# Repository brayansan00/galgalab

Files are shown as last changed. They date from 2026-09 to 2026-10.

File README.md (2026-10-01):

# GalgaLab

Comparación de teoría de vigas, ensayo con galga extensiométrica y FEM de una viga tubular de aluminio 1100. Revisión del ZIP frente a `main` en el commit `dfa231fbb436338dee7460102a4b27766cca2854` (30 de septiembre de 2026).

## Estado y resultados

El cálculo y el tratamiento del CSV son reproducibles. La validación física sigue pendiente: no se recuerda si el herraje de 73 g estaba instalado al poner la galga en cero. Se conservan ambos casos, sin escoger uno como confirmado.

| Referencia experimental | Carga incremental | Teoría en la galga | Diferencia del ensayo respecto a teoría |
|---|---:|---:|---:|
| Herraje añadido después del cero | 49,76613 N | 11,39852 MPa; 165,1959 µε | +10,08 % |
| Herraje presente al poner en cero | 49,05000 N | 11,23449 MPa; 162,8187 µε | +11,69 % |

El ensayo da 185,31171 µε en la meseta; la base previa es 3,46042 µε. El incremento es 181,85128 µε y su esfuerzo equivalente uniaxial es 12,54774 MPa con E = 69 GPa. La desviación de la meseta (0,86 µε) es dispersión de muestras, no incertidumbre total.

Las cifras suponen que el canal exportado ya contiene deformación adimensional y que la rejilla está centrada en la marca CAD y alineada con el eje longitudinal **y**. Falta comprobarlo con el montaje y la configuración de adquisición.

**FEM en revisión.** Las mallas usaron dos fuerzas de 24,883 N en y = 707 mm, con componente vertical conjunta de 46,764 N y gravedad activa. El informe histórico del 24 de septiembre contiene otra configuración: dos fuerzas de 28,106 N y total vertical 52,822 N más gravedad. Las exportaciones anteriores de 10 y 15 mm repetían recuentos y resúmenes; la nueva exportación de 15 mm corrige esa repetición.

**Actualización del 30 de septiembre:** los nuevos informes tienen 80 346 nodos / 40 572 elementos para 10 mm y 48 735 / 24 301 para 15 mm. Las capturas, identificadas como Von Mises por el usuario, dan 10,984 y 10,926 MPa en el mismo punto (17; 205; 29,997) mm: variación de 0,528 % respecto a la malla refinada. Es evidencia de estabilidad puntual entre dos mallas; falta confirmar convergencia con otro refinamiento y comparar la magnitud longitudinal en la rejilla. Véase `fem/mesh_study/actualizacion_2026-09-30/README.md`.

## Reproducir

Desde la raíz del repositorio:

```text
python -m pip install -r requirements.txt
python python/analisis_viga.py
python python/auditar_fem.py
python -m unittest discover -s tests -v
```

El análisis acepta `--csv RUTA`, `--baseline INICIO FIN`, `--plateau INICIO FIN` y `--output-dir CARPETA`. Las ventanas por defecto son inclusivas: base 11–16,5 s (551 muestras), meseta 24–53 s (2 901 muestras). El CSV original conserva 7 744 muestras y 77,43 s a 100 Hz. Se rechazan archivos o ventanas inválidos.

## Archivos

- `python/analisis_viga.py`: modelo, ensayo, sensibilidad de espesor y figuras; `analytical_model.py` conserva la entrada anterior.
- `experimental/raw_data/`: originales; se conservan tanto el archivo previo del grupo 1 como el ensayo Samuel–Brayan. Solo este último alimenta el análisis por defecto.
- `experimental/processed_data/`: señal procesada y resultados JSON, con huella SHA-256 del original.
- `cad/`: STEP actualizado, archivo nativo recibido y verificación geométrica. El archivo Fusion no se ha resuelto ni editado.
- `fem/`: informes vigentes de 10 y 15 mm, exportaciones anteriores conservadas en `mesh_study/historico_2026-09-25/`, auditoría y procedimiento para nuevas corridas.
- `figures/`: gráficas calculadas; `report/informe_viga.tex`: borrador revisado, autónomo con figuras vectoriales incorporadas.
- `report/informe_viga_revisado.pdf`: versión de lectura generada desde los resultados; la compilación LaTeX del editor integrado falló por un problema de entorno y no está verificada.
- `report/original/`: PDF y fuente recibidos, archivados como borrador anterior; no representan la revisión actual.
- `REVISION_CAMBIOS.md`: comparación, opinión y pendientes.

## Para cerrar la validación

Confirmar orientación y centro real de la rejilla, espesor medido, posición de carga y estado de referencia; configurar apoyo y contactos; repetir mallas con la misma carga incremental; comparar **εyy promediada sobre la rejilla** y σyy local, y verificar equilibrio sumando reacciones. Von Mises máximo global no sustituye la lectura de la galga.

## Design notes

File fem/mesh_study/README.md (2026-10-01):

# Estudio de malla

Las mallas de **10 y 15 mm** se actualizaron con los informes y capturas exportados el 30 de septiembre de 2026. Los HTML se conservan completos y las capturas mantienen su formato PNG original. Las imágenes anteriores de esas dos mallas se sustituyeron; Git conserva sus versiones previas.

| Malla | Informe de Fusion | Captura | Nodos | Elementos | Von Mises máximo global (MPa) | Von Mises en el punto (MPa) |
|---:|---|---|---:|---:|---:|---:|
| 10 mm | [10mm.html](10mm.html) | [10mm.png](10mm.png) | 80 346 | 40 572 | 21,018 | 10,984 |
| 15 mm | [15 mm.html](15%20mm.html) | [15mm.png](15mm.png) | 48 735 | 24 301 | 20,722 | 10,926 |

Los recuentos y máximos globales proceden de los HTML. Las lecturas puntuales proceden de las etiquetas de las capturas; el autor confirmó que el resultado seleccionado era **Von Mises**. Ambas etiquetas indican (x, y, z) = (17,000; 205,000; 29,997) mm.

La diferencia puntual es 0,058 MPa: **0,5280 %** respecto a la malla de 10 mm. Estos dos resultados muestran baja sensibilidad local al refinamiento, pero todavía no acreditan convergencia definitiva ni equivalencia con la deformación longitudinal medida por la galga. No se ejecutó una nueva simulación para esta actualización.

Ambos HTML exportan dos fuerzas remotas de 24,883 N, con componente Z de −23,382 N por lado, posición remota y = 707 mm y gravedad de 9,807 m/s². El modelo analizado figura como `VIGA_FEM v25` en 10 mm y `VIGA_FEM v26` en 15 mm. Aún debe comprobarse la correspondencia de esta configuración con la carga y el estado de referencia del ensayo.

## Captura de la malla de 10 mm

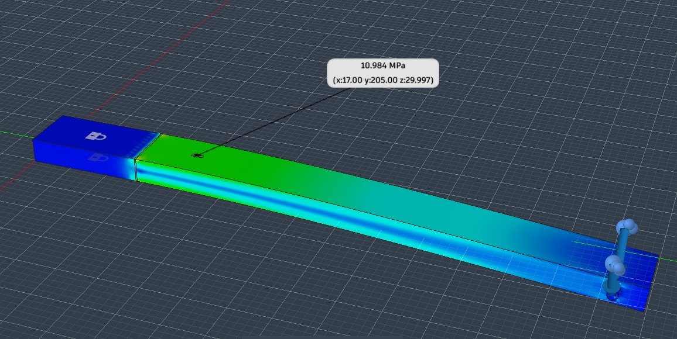
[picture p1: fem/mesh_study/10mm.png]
Von Mises de la malla de 10 mm: 10,984 MPa en el punto señalado


## Captura de la malla de 15 mm

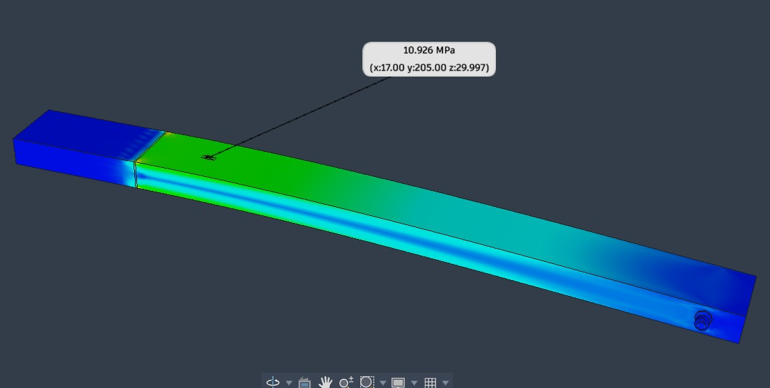
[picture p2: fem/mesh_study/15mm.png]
Von Mises de la malla de 15 mm: 10,926 MPa en el punto señalado


Los archivos de las mallas de 5, 20 y 25 mm corresponden a las exportaciones anteriores.

Los dos HTML anteriores de 10 y 15 mm se conservan en [historico_2026-09-25/](historico_2026-09-25/), con sus recuentos repetidos originales. La comprobación analítica orientativa y el detalle de esta actualización están en [actualizacion_2026-09-30/README.md](actualizacion_2026-09-30/README.md).

## Extracción longitudinal y validación pendientes

1. Fijar geometría, material, referencia, contactos y apoyo; comprobar y ≈ 711 mm y el centro real de la rejilla. Conservar ambos estados del herraje mientras no se confirme la puesta a cero.
2. Para la flexión global incremental, usar P = 49,05 o 49,76613 N. Si se reparte en dos fuerzas equivalentes a 20°, usar 26,09896 o 26,48000 N por lado; documentar objetivos, aplicación y momentos remotos. Excluir cargas ya presentes en la referencia. Véase [LEEME_FEM.md](../../cad/LEEME_FEM.md) para peso del herraje y contacto.
3. Regenerar y resolver cada malla, exportando fecha, nodos, elementos, tamaños efectivos locales y capturas. El tamaño global nominal no demuestra resolución suficiente a través de 1 mm de pared. Justificar sólidos, refinamiento en espesor o un modelo de cascarones.
4. Extraer εyy y σyy en la misma rejilla sensible, preferiblemente promedio espacial ponderado sobre 2,5 × 10 mm; conservar también valor central y tensor local. Si cambia el sistema de coordenadas, proyectar sobre la dirección real de la galga.
5. Comprobar la suma vectorial de reacciones y momentos, más calidad de elementos y ausencia de cuerpos libres. No sumar los máximos de un resumen de reacciones.
6. Calcular variación de la lectura de galga entre refinamientos. Definir el criterio de aceptación antes de interpretar la tabla (p. ej., 2 % si lo permite el curso) y documentar al menos dos refinamientos sucesivos que lo cumplan. Es un criterio propuesto, no una exigencia del profesor ni garantía absoluta de exactitud.

En isotropía lineal, εyy = [σyy − ν(σxx + σzz)]/E. Una superficie libre solo anula las tracciones normales a ella; no obliga a σxx = 0. Comparar directamente εyy evita identificar Eεyy con σyy cuando existen otras componentes. Von Mises puede acompañar el análisis, pero no reemplaza la lectura longitudinal.

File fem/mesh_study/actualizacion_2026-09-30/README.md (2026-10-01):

# Actualización de las mallas de 10 y 15 mm

Se añadieron los dos HTML y las dos capturas originales enviados después de la primera revisión. El usuario identifica la primera captura con 10 mm, la segunda con 15 mm y confirma que la variable seleccionada es **Von Mises**. Las lecturas puntuales proceden de las imágenes; los recuentos, máximos globales y cargas proceden de los HTML. No se ejecutó el solver durante esta revisión.

| Malla | Nodos | Elementos | Von Mises global máximo [MPa] | Von Mises en el punto [MPa] |
|---:|---:|---:|---:|---:|
| 15 mm | 48 735 | 24 301 | 20,722 | 10,926 |
| 10 mm | 80 346 | 40 572 | 21,018 | 10,984 |

Ambas etiquetas señalan (x, y, z) = (17,000; 205,000; 29,997) mm. La diferencia es 0,058 MPa. Respecto a la malla refinada: |10,984 − 10,926| / 10,984 × 100 = **0,5280 %**. Esto indica baja sensibilidad local entre estas dos resoluciones, pero no demuestra por sí solo independencia de malla definitiva. Falta al menos otro refinamiento consistente y la lectura longitudinal/promedio de rejilla que se desea contrastar con el experimento.

La nueva exportación de 15 mm sí tiene recuentos y resultados distintos. La repetición señalada en la revisión inicial pertenece al HTML anterior [15 mm.html](../historico_2026-09-25/15%20mm.html), conservado como historial. El [HTML vigente de 10 mm](../10mm.html) mantiene los recuentos y máximos de su exportación anterior, pero las capturas aportan ahora una lectura local.

## Configuración que todavía debe reconciliarse

Los [informes vigentes de 10 mm](../10mm.html) y [15 mm](../15%20mm.html) conservan dos fuerzas remotas de 24,883 N, componentes Z de −23,382 N por lado, punto remoto y = 707 mm y gravedad 9,807 m/s². Materiales, propiedades, siete contactos fijados y restricción fija Ux/Uy/Uz coinciden en lo exportado. El archivo analizado cambia de `VIGA_FEM v25` a `v26`: esto no acredita identidad geométrica exacta entre versiones.

La fuerza vertical conjunta es 46,764 N, más peso propio. Para el caso incremental definido en el análisis del ensayo aún corresponde revisar P = 49,05 o 49,76613 N, posición y ≈ 711 mm y tratamiento de gravedad según el estado de referencia.

## Comprobación analítica orientativa de la corrida actual

Se usaron los parámetros nominales y las propiedades de estos HTML: área A = 70×30 − 68×28 = 196 mm²; I = 33 105,33333 mm⁴; c = 15 mm; densidad ρ = 2,700×10⁻⁶ kg/mm³; g = 9,807 m/s². El peso lineal nominal es q = Aρg = 0,0051898644 N/mm.

En y = 205 mm, la flexión por las fuerzas exportadas es 46,764×(707−205)×15/I = **10,636743 MPa**. El peso de la viga hasta y = 746 mm aporta q×(746−205)²×15/(2I) = **0,344123 MPa**. La suma aproximada es **10,980866 MPa**, cercana a la lectura de 10,984 MPa.

Si también se incluye el peso del herraje CAD idealizado, su volumen verificado de 6 270,824 mm³ y la densidad exportada dan 16,932 g. Concentrarlo aproximadamente en y = 711 mm añade 0,038069 MPa: total **11,018935 MPa**. La comparación sirve como comprobación orientativa de la configuración actual, no como error certificado ni equivalencia exacta entre Von Mises y esfuerzo longitudinal. Ignora detalles de contacto, hueco y geometría local; los 16,932 g idealizados tampoco sustituyen los 73 g medidos.

El punto mostrado está cerca del centro CAD (16,568677; 205,5; 30) mm, pero no coincide exactamente con él. Ninguna de estas etiquetas es el promedio sobre la rejilla sensible de 2,5×10 mm. Las imágenes originales están en [10mm.png](../10mm.png) y [15mm.png](../15mm.png), y los datos trazables en [lecturas_galga.json](../lecturas_galga.json).

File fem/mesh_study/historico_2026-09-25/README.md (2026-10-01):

# Exportaciones anteriores de 10 y 15 mm

Copias exactas de los HTML disponibles en el commit `dfa231f` del 25 de septiembre de 2026, antes de sustituirlos por las nuevas exportaciones. Estos dos archivos repetían recuentos y máximos; no representan los resultados vigentes. Los informes actuales están en [10mm.html](../10mm.html) y [15 mm.html](../15%20mm.html).

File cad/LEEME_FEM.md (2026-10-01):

# Geometría recibida y preparación FEM

Los archivos disponibles son `step/VIGA_FEM.step` y `native/VIGA_FEMa.f3d`. El texto anterior mencionaba un FreeCAD editable y archivos de vista que no están en el repositorio; no se ofrecen como entregables.

## Comparación verificada

Se reimportaron los STEP de GitHub (`dfa231f`) y del ZIP con Open CASCADE. Ambos conjuntos son válidos y contienen siete sólidos. Los volúmenes y límites por sólido coinciden dentro de precisión numérica. La viga ocupa y = 0–746 mm y z = 0–30 mm, con ancho aproximado 70 mm. El borde de división CAD próximo a la mordaza es y = 141,831516 mm; esa división geométrica no confirma por sí sola el apoyo experimental.

La cara de la marca de galga tenía 75 mm² y centro (16,568677; 205,5; 30) mm. El STEP nuevo la divide en cuatro caras de 18,75 mm², manteniendo área y centro ponderado. Es una partición útil para seleccionar el centro. **No garantiza que la rejilla real de 2,5 × 10 mm esté centrada ni que un valor nodal represente su promedio.**

Los valores completos están en `Verificacion_geometria.json`. Esta revisión comprueba validez, volúmenes, límites y caras de galga; no certifica todos los contactos mecánicos ni ejecuta un solver. El `.f3d` se conserva exactamente como fue recibido; su configuración activa no se ha inspeccionado en Fusion.

## Idealizaciones heredadas

Tornillo de diámetro nominal 8 mm, dos arandelas y cierre idealizado, con huecos axiales para la cuerda. La masa medida del herraje es 73 g; no se debe obtener de su volumen idealizado. En las exportaciones antiguas todas las piezas usan aluminio 1100-O, E = 68 947,20 MPa, ν = 0,33 y densidad 2,700 × 10⁻⁶ kg/mm³. Son propiedades de esas corridas, no mediciones nuevas ni confirmación del material real del tornillo. El análisis comparativo adopta E = 69 000 MPa. En el STEP, las propiedades de material no constituyen una definición completa del estudio FEM.

## Carga y referencia

Con g = 9,81 m/s², la pesa aporta 49,05 N y el herraje 0,71613 N. Si estaba presente al poner en cero, este último peso pertenece a la referencia y el incremento experimental es solo 49,05 N. Si se añadió después, el incremento conjunto es 49,76613 N. El usuario no recuerda esta condición: se conservan ambos escenarios.

Dos fuerzas equivalentes simétricas a 20° respecto a vertical valen 26,09896 N por lado para 49,05 N, o 26,48000 N para 49,76613 N. En coordenadas del CAD, Z es vertical y Y longitudinal. Las componentes horizontales se cancelan globalmente. La tensión física de cada cuerda debida a la pesa de 5 kg es 26,09896 N; incluir el peso del herraje en las cuerdas es una simplificación de carga equivalente para flexión global. Para esfuerzos locales, aplicar su peso por separado en la posición real.

Para comparar incrementos elásticos manteniendo los mismos contactos, se puede excluir gravedad y aplicar solo la carga incremental. Otra opción es restar resultados de estado cargado y referencia. No sumar el peso del herraje dos veces. Si cambian contacto o pretensión, justificar el modelo incremental; no suponer superposición sin comprobarla.

## Antes de resolver

Definir zona de mordaza del ensayo, conectar las tres regiones de viga según su continuidad física y justificar contactos tornillo–agujero, arandelas y cierre. Evitar cuerpos libres y uniones automáticas sin fundamento. Comprobar eje del agujero y punto efectivo de carga (CAD: y ≈ 711 mm); documentar qué caras reciben fuerzas remotas y los momentos que estas transfieren. Verificar el equilibrio de la suma de reacciones, la calidad de malla en la pared de 1 mm y la lectura longitudinal en la rejilla.

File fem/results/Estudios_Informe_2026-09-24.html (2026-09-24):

- Encabezamiento
- Propiedades del informe
- Modelo de simulación 1
  - Estudio 1: tensión estática
    - Propiedades del estudio
    - Configuración del estudio
      - Configuración
      - Materiales
      - Contactos
      - Malla
      - Caso de carga1
        - Restricciones
        - Cargas
        - Resultados guiados
          - Factor de seguridad
        - Resultados
          - Resumen de resultados
          - Factor de seguridad
          - Estrés
          - Desplazamiento

Informe del estudio 2

Archivo analizado | VIGA_FEM v6 | Versión | Autodesk Fusion (2704.1.53)
Fecha de creación | 2026-09-24, 01:15:38 | Autor | braya

Propiedades del informe

Propiedades del informe
Título | Estudios
Autor | braya

Modelo de simulación 1

Estudio 1: tensión estática

Propiedades del estudio

Propiedades del estudio
Tipo de estudio | Tensión estática
Fecha de la última modificación | 2026-09-24, 01:11:22

Configuración del estudio

Configuración
General

Tolerancia de contacto | 0.01 mm
Eliminar los modos de cuerpos rígidos | No
Malla

Tamaño medio de elemento (% del tamaño del modelo) - Sólidos | 9
Escala de tamaño de malla por pieza | Sí
Tamaño medio de elemento (valor absoluto) | -
Orden de elemento | Parabólico
Crear elementos de malla curva | Sí
Ángulo de giro máx. en curvas (grad.) | 55
Relación de tamaño máx. de malla adyacente | 1.5
Relación de aspecto máxima | 10
Tamaño mínimo de elemento (% del tamaño medio) | 30
Refinado de malla adaptable

Número de pasos de refinado | 0
Tolerancia de convergencia de resultados (%) | 20
Parte de los elementos para refinar (%) | 10
Resultados para la precisión de la línea base | Tensión de von Mises

Materiales
Aluminio 1100-O
Componentes

Componente | Resistencia
Arandela_lado_cuerda:1 | Límite de elasticidad
Arandela_opuesta:1 | Límite de elasticidad
Tornillo:1 | Límite de elasticidad
Tuerca_cierre_idealizada:1 | Límite de elasticidad
Viga y galga - geometria original intacta:1/Cuerpo1 | Límite de elasticidad
Viga y galga - geometria original intacta:1/Cuerpo2 | Límite de elasticidad
Viga y galga - geometria original intacta:1/Cuerpo3 | Límite de elasticidad
Propiedades

Densidad | 2.700E-06 kg / mm^3
Módulo de Young | 68947.20 MPa
Coeficiente de Poisson | 0.33
Límite de elasticidad | 34.474 MPa
Resistencia máxima a tracción | 89.631 MPa
Conductividad térmica | 0.222 W / (mm C)
Coeficiente de dilatación térmica | 2.358E-05 / C
Calor específico | 900.00 J / (kg C)

Contactos
Contact Type | Contact Set | Penetration Type | Bodies | Entities
Fijado

Fijado1 | Simétrico | [Cuerpo1 Tornillo:1||Cuerpo1 Tuerca_cierre_idealizada:1] | [Cara 0||Cara 3]
Fijado2 | Simétrico | [Cuerpo3 Viga y galga - geometria original intacta:1||Cuerpo1 Arandela_opuesta:1] | [Cara 75||Cara 1]
Fijado3 | Simétrico | [Cuerpo3 Viga y galga - geometria original intacta:1||Cuerpo1 Arandela_lado_cuerda:1] | [Cara 72||Cara 2]
Fijado4 | Simétrico | [Cuerpo3 Viga y galga - geometria original intacta:1||Cuerpo1 Tornillo:1] | [Cara 69||Cara 0]
Fijado5 | Simétrico | [Cuerpo3 Viga y galga - geometria original intacta:1||Cuerpo1 Tornillo:1] | [Cara 68||Cara 0]
Fijado6 | Simétrico | [Cuerpo1 Viga y galga - geometria original intacta:1||Cuerpo2 Viga y galga - geometria original intacta:1] | [Cara 9||Cara 34]
Fijado7 | Simétrico | [Cuerpo1 Viga y galga - geometria original intacta:1||Cuerpo3 Viga y galga - geometria original intacta:1] | [Cara 8||Cara 71]

Malla
Tipo | Sólidos
Nodos | 82873
Elementos | 41587

Caso de carga1

Restricciones
Fijo1
Tipo | Fijo
Ux | Fijo
Uy | Fijo
Uz | Fijo

Cargas
Gravedad
Tipo | Gravedad
Magnitud | 9.807 m / s^2
Valor X | 0.00 m / s^2
Valor Y | 0.00 m / s^2
Valor Z | -9.807 m / s^2
Fuerza remota1

Tipo | Fuerza remota
Magnitud | 28.106 N
Valor X | -9.613 N
Valor Y | 0.00 N
Valor Z | -26.411 N
Ángulo X | 20.0 deg
Ángulo Y | 90.0 deg
Ángulo Z | 0.0 deg
Posición X | 55.00 mm
Posición Y | 707.00 mm
Posición Z | 17.00 mm
Fuerza remota2

Tipo | Fuerza remota
Magnitud | 28.106 N
Valor X | 9.613 N
Valor Y | 0.00 N
Valor Z | -26.411 N
Ángulo X | -20.0 deg
Ángulo Y | 90.0 deg
Ángulo Z | 0.0 deg
Posición X | -20.00 mm
Posición Y | 707.00 mm
Posición Z | 17.00 mm

Caso de carga1 - Resultados guiados

Factor de seguridad

Con los criterios de análisis de esta configuración del estudio, se espera que el diseño se doble de forma permanente o se rompa.

Pasos siguientes

Por debajo del objetivo del factor de seguridad

Validar la configuración del estudio

Comprobar que las cargas no se hayan establecido en un nivel demasiado alto

Comprobar el refinado de la malla y considerar la posibilidad de aumentarlo en áreas con alta tensión

Confirmar requisito de factor de seguridad

Si el resultado del desplazamiento muestra un desplazamiento elevado, considere la posibilidad de ejecutar un estudio no lineal para obtener más información

Comprobar otros resultados

Examine la visualización de resultados por debajo del objetivo para ver dónde se encuentran las áreas más débiles

Compruebe el resultado de esfuerzo para ver si el material puede deformarse y dónde puede hacerlo

Compruebe el resultado del desplazamiento para ver a qué distancia de su alineación original se ha desplazado el modelo

Examine otros resultados, como las fuerzas de reacción para comprobar la configuración del estudio o la deformación para comprobar el rendimiento del material.

Reforzar áreas débiles

Añadir más material a las áreas débiles

Seleccionar un material con un límite de elasticidad mayor

Hacer el diseño más rígido

Modificar la forma con un estudio de diseño generativo

Generar diseños alternativos

Añadir más material a las áreas débiles

Seleccionar un material con un límite de elasticidad mayor

Hacer el diseño más rígido

Modificar la forma con un estudio de diseño generativo

Cumple con el objetivo del factor de seguridad

Validar la configuración del estudio

Comprobar que las cargas no se hayan establecido en un nivel demasiado alto

Comprobar el refinado de la malla y considerar la posibilidad de aumentarlo en áreas con alta tensión

Confirmar requisito de factor de seguridad

Si el resultado del desplazamiento muestra un desplazamiento elevado, considere la posibilidad de ejecutar un estudio no lineal para obtener más información

Comprobar otros resultados

Examine la visualización de resultados por debajo del objetivo para ver dónde se encuentran las áreas más débiles

Compruebe el resultado de esfuerzo para ver si el material puede deformarse y dónde puede hacerlo

Compruebe el resultado del desplazamiento para ver a qué distancia de su alineación original se ha desplazado el modelo

Examine otros resultados, como las fuerzas de reacción para comprobar la configuración del estudio o la deformación para comprobar el rendimiento del material.

Por encima del límite del factor de seguridad

Validar la configuración del estudio

Comprobar que las cargas no se hayan establecido en un nivel demasiado alto

Comprobar el refinado de la malla y considerar la posibilidad de aumentarlo en áreas con alta tensión

Confirmar requisito de factor de seguridad

Si el resultado del desplazamiento muestra un desplazamiento elevado, considere la posibilidad de ejecutar un estudio no lineal para obtener más información

Comprobar otros resultados

Examine la visualización de resultados por debajo del objetivo para ver dónde se encuentran las áreas más débiles

Compruebe el resultado de esfuerzo para ver si el material puede deformarse y dónde puede hacerlo

Compruebe el resultado del desplazamiento para ver a qué distancia de su alineación original se ha desplazado el modelo

Examine otros resultados, como las fuerzas de reacción para comprobar la configuración del estudio o la deformación para comprobar el rendimiento del material.

Hacer el diseño más ligero

Establecer un límite superior del factor de seguridad para encontrar dónde se puede eliminar material

Eliminar material de áreas que superen el límite superior del factor de seguridad

Generar diseños alternativos

En el espacio de trabajo Diseño generativo, cree modificaciones de diseño

Eliminar material innecesario mediante un estudio de optimización de formas

Caso de carga1 - Resultados

Resumen de resultados
Tipo de resultado | Subresultado | Mínimo | Máximo
Factor de seguridad

Factor de seguridad | 1.489 | 5.853E+07
Tensión

Von Mises | 5.89E-07 MPa | 23.146 MPa
Primera principal | −4.111 MPa | 25.635 MPa
Tercera principal | −26.576 MPa | 4.12 MPa
Normal XX | −7.032 MPa | 7.02 MPa
Normal YY | −25.628 MPa | 24.796 MPa
Normal ZZ | −6.002 MPa | 5.997 MPa
Corte XY | −4.149 MPa | 4.759 MPa
Corte YZ | −3.767 MPa | 1.451 MPa
Corte XZ | −3.333 MPa | 2.432 MPa
Desplazamiento

Total | 0 mm | 1.608 mm
X | −0.002 mm | 0.002 mm
Y | −0.057 mm | 0.057 mm
Z | −1.607 mm | 6.046E-04 mm
Fuerza de reacción

Total | 0 N | 90.288 N
X | −22.758 N | 22.192 N
Y | −87.135 N | 86.913 N
Z | −10.681 N | 6.931 N
Deformación

Equivalente | 1.136E-11 | 3.589E-04
Primera principal | −6.661E-07 | 3.826E-04
Tercera principal | −3.972E-04 | 3.465E-07
Normal XX | −1.016E-04 | 1.037E-04
Normal YY | −3.329E-04 | 3.253E-04
Normal ZZ | −1.068E-04 | 1.044E-04
Corte XY | −1.601E-04 | 1.836E-04
Corte YZ | −1.453E-04 | 5.597E-05
Corte XZ | −1.286E-04 | 9.383E-05
Presión de contacto

Total | 0 MPa | 26.048 MPa
X | −4.759 MPa | 4.149 MPa
Y | −24.796 MPa | 25.628 MPa
Z | −3.767 MPa | 4.169 MPa
Fuerza de contacto

Total | 0 N | 85.293 N
X | −25.187 N | 24.287 N
Y | −80.769 N | 80.591 N
Z | −14.259 N | 13.545 N

Factor de seguridad

Factor de seguridad

Estrés

Von Mises

$$ImageCompatibilityInfo$

Primera principal

$$ImageCompatibilityInfo$

Tercera principal

$$ImageCompatibilityInfo$

Desplazamiento

Total

$$ImageCompatibilityInfo$

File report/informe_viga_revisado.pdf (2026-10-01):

GalgaLab · Borrador revisado · 30/09/2026 | 1

GALGALAB · REVISIÓN DEL REPOSITORIO

# Una viga, dos estados de referencia

## Teoría de vigas, ensayo con galga extensiométrica y auditoría FEM

Brayan y Samuel · Universidad Pontificia Bolivariana, Medellín
Elementos Finitos · Profesor Elkin Alonso Taborda Espinosa

Revisión: 30 de septiembre de 2026. Fecha de entrega indicada en el borrador: 6 de octubre de 2026. Apellidos pendientes.

Los cambios del ZIP mejoran el proyecto. La aritmética del análisis y el procesamiento del ensayo son reproducibles. La comparación FEM todavía requiere correcciones y nuevas corridas.

Se revisó el ZIP frente a brayansan00/galgalab, (https://github.com/brayansan00/galgalab) rama main, commit dfa231f. El estado del herraje al poner la galga en cero no se recuerda; se conservan ambas posibilidades.

Escenario | Carga incremental | Teoría en galga | Diferencia neta
A · Herraje añadido después del cero | 49,76613 N | 11,39852 MPa | +10,08 %
B · Herraje presente al poner en cero | 49,05000 N | 11,23449 MPa | +11,69 %

El ensayo corregido da 181,85128 µε, equivalente a 12,54774 MPa con E = 69 GPa bajo hipótesis uniaxial. La diferencia no constituye por sí sola una validación ni un rechazo.

Dato adoptado | Valor
Sección nominal / pared | 70 × 30 mm / 1 mm
Longitud total | 746 mm
Galga: centro CAD / rejilla indicada | y = 205,5 mm / 2,5 × 10 mm
Carga / borde de mordaza CAD | y ≈ 711 mm / y ≈ 141,83152 mm
Pesa / herraje medido | 5 kg / 0,073 kg

Las coordenadas CAD, la orientación y el centro supuesto de rejilla deben comprobarse en el montaje. El canal del CSV se interpreta como deformación adimensional ya convertida.

## 1. Modelo analítico y magnitud comparada

Se adopta flexión global de Euler–Bernoulli: elasticidad lineal, pequeñas deformaciones y tubo nominal con altura vertical de 30 mm. En el CAD, y es longitudinal y z vertical. El esfuerzo longitudinal es σyy.

I = [70·30³ − 68·28³]/12 = 33 105,33333 mm⁴
c = 15 mm; a = 711 − 205,5 = 505,5 mm.
M(y) = P·(yP − y); σyy = Mc/I; εyy = σyy/E en el modelo uniaxial.

En A: M en galga = 25 156,778715 N·mm; σyy = 11,398516 MPa; εyy = 165,195888 µε. En B: σyy = 11,234493 MPa; εyy = 162,818734 µε.

Si la rejilla de 10 mm está centrada, el promedio longitudinal coincide con el centro por la linealidad del momento. En A sus extremos dan 11,51126 y 11,28577 MPa. La marca CAD de 15 mm tiene otros extremos y no debe confundirse con la rejilla.

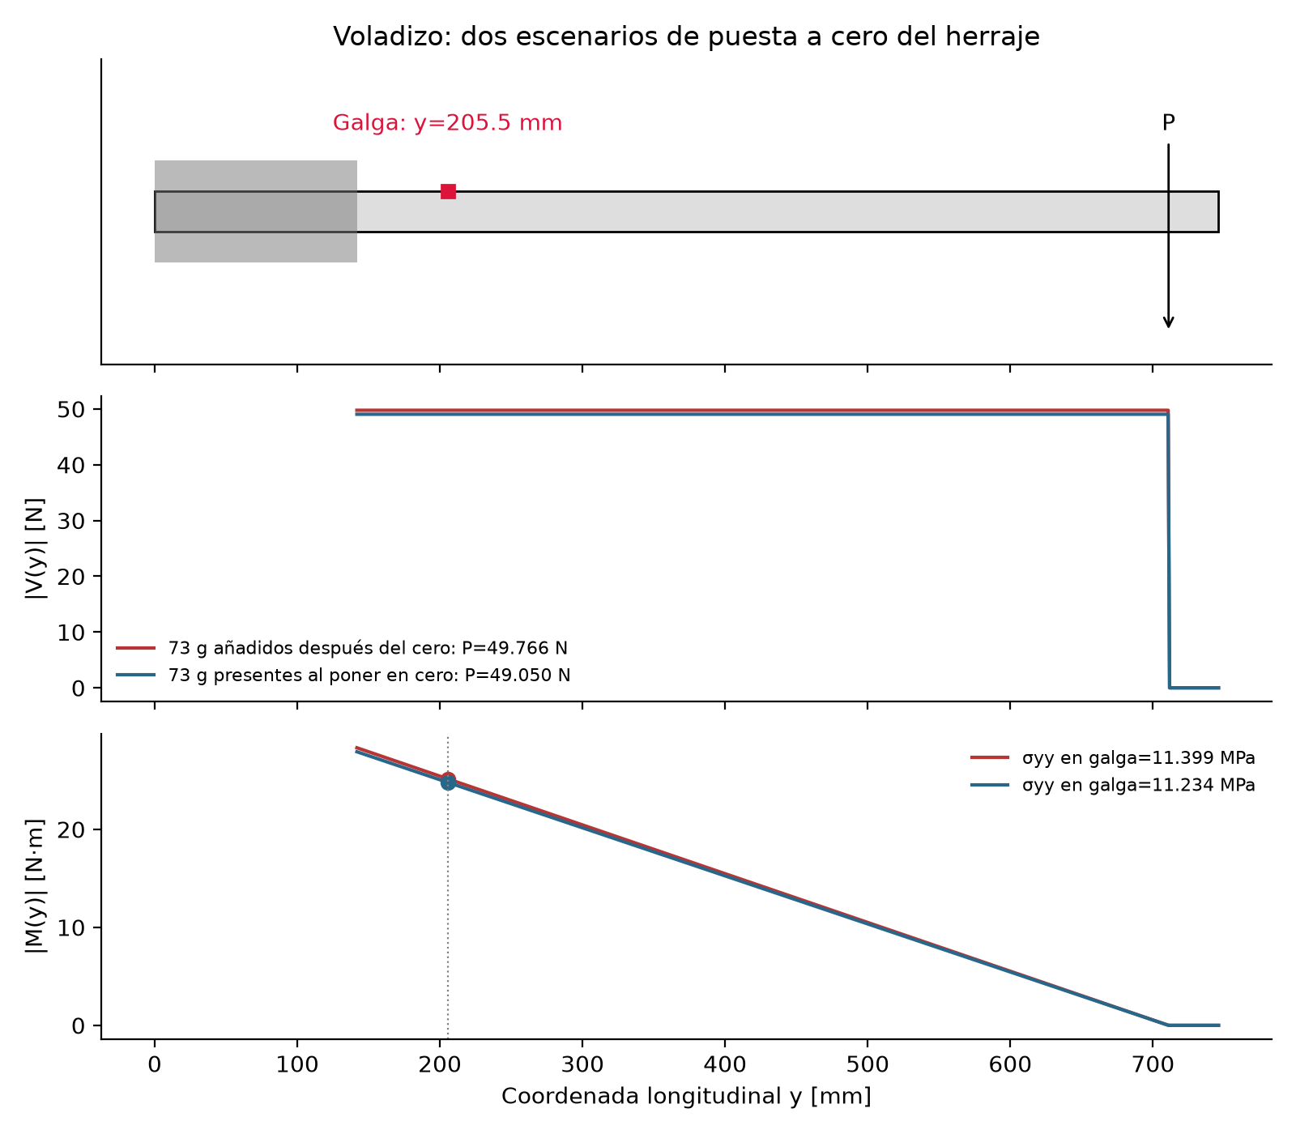
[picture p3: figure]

Figura 1. Magnitudes de cortante y momento para los dos estados del herraje; después de la carga son cero en este modelo sin peso propio.

Una superficie libre de normal z no garantiza estado uniaxial. En isotropía lineal, εyy = [σyy − ν(σxx + σzz)]/E. Por eso, la comparación FEM más directa es la deformación en la dirección real de la galga; Von Mises es complementario.

## 2. Ensayo: del CSV al incremento de carga

Archivo: Viga4SamuelBrayan.csv. Se mantienen intactas las 7 744 muestras y el otro CSV previo del repositorio. El ensayo dura 77,43 s y tiene pasos de 0,01 s, equivalentes a 100 Hz.

El análisis usa ventanas inclusivas, seleccionadas fuera de la rampa y de la descarga. Resta la media inmediatamente anterior a la carga; no trata la señal cruda como si su base fuera exactamente cero.

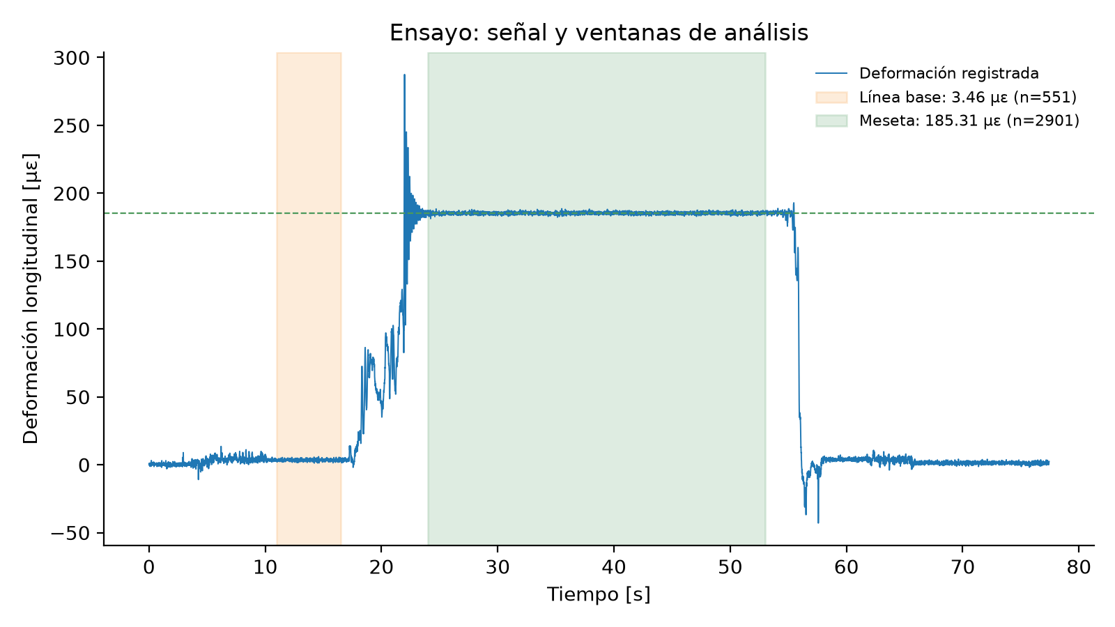
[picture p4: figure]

Figura 2. Datos del ensayo, línea base previa y meseta. Todas las muestras de cada ventana entran en sus estadísticas.

Magnitud | Valor / ventana
Línea base previa | 11–16,5 s; 551 muestras
Meseta | 24–53 s; 2 901 muestras
Media de meseta | 185,31171 µε
Media de base | 3,46042 µε
Incremento meseta − base | 181,85128 µε
Desviación muestral en meseta | 0,85688 µε
Esfuerzo equivalente crudo / neto | 12,78651 / 12,54774 MPa

La desviación de muestras describe dispersión temporal, no la incertidumbre total. No se asume independencia de muestras ni se presenta una incertidumbre de media sin estudiar autocorrelación.

Pendiente: confirmar unidades del canal, configuración de adquisición, factor de galga, calibración y orientación sensible. La inferencia de esfuerzo equivalente requiere la hipótesis uniaxial.

## 3. CAD y configuraciones FEM históricas

Los dos STEP se reimportaron con Open CASCADE. Ambos contienen siete sólidos válidos; sus volúmenes y límites coinciden dentro de precisión numérica. La marca de galga pasa de una cara de 75 mm² a cuatro de 18,75 mm², conservando centro ponderado (16,568677; 205,5; 30) mm.

La partición ayuda a seleccionar el centro, pero no acredita el promedio sobre la rejilla real. Se conserva el archivo Fusion recibido; no se ha inspeccionado su estudio activo ni se ha resuelto FEM.

Conjunto exportado | | Fuerzas verticales | Gravedad
Informe 23 de septiembre | | −49,05 N | 9,807 m/s²
Informe 24 de septiembre | | −52,822 N | 9,807 m/s²
Cinco mallas históricas | | −46,764 N | 9,807 m/s²

El informe del 24 usa dos fuerzas de 28,106 N. Las mallas usan dos de 24,883 N en y = 707 mm. La nota del ZIP que atribuía esta última configuración a todas las corridas era incorrecta. Los totales de la tabla excluyen peso propio.

Malla nominal | Nodos | Elementos | VM máximo global [MPa]
25 mm | 28 614 | 13 899 | 17,535
20 mm | 46 004 | 22 549 | 20,453
15 mm | 80 346 | 40 572 | 21,018
10 mm | 80 346 | 40 572 | 21,018
5 mm | 86 283 | 42 748 | 20,863

Las exportaciones anteriores de 10 y 15 mm repetían recuentos y resúmenes. La nueva exportación de 15 mm corrige esa repetición; la actualización al final de este informe contiene sus datos y lecturas puntuales. La diferencia entre máximos globales no certifica convergencia en la galga.

Son sólidos parabólicos con escalado por pieza. Falta documentar resolución local de la pared de 1 mm, calidad de elementos, apoyo, contactos y equilibrio mediante sumas de reacciones; los máximos de reacción no son esas sumas.

## 4. Comparación, sensibilidad y criterio físico

Resultado | Escenario A | Escenario B
Teoría σyy [MPa] | 11,39852 | 11,23449
Teoría εyy [µε] | 165,1959 | 162,8187
Ensayo neto ε [µε] | 181,8513 | 181,8513
Ensayo equivalente [MPa] | 12,54774 | 12,54774
Diferencia neta respecto a teoría | +10,08 % | +11,69 %
FEM en la misma rejilla | Pendiente | Pendiente

Espesor. Para A, t = 0,95 mm da 11,94799 MPa (+4,82 %); t = 1,05 mm da 10,90159 MPa (−4,36 %); t = 0,90 mm da 12,55876 MPa. Es sensibilidad, no una medida del espesor real. No ajustar una dimensión para hacer coincidir el ensayo; medir pared y radios de esquina.

Geometría. Una variación supuesta de 3 mm en el brazo cambia el resultado un 0,59 %. No se presenta como incertidumbre medida. La galga está a unos 63,67 mm del borde CAD de mordaza; los efectos locales deben revisarse.

Material. Los HTML usan E = 68 947,20 MPa y ν = 0,33; el análisis usa E = 69 000 MPa. La diferencia de módulo (0,077 %) no explica por sí sola el desajuste. Todos los cuerpos antiguos figuran como aluminio 1100-O; eso no confirma el material real del tornillo.

Fuerzas. Dos cargas equivalentes a 20° son 26,48000 N por lado para A o 26,09896 N para B. La tensión de cada cuerda debida solo a la pesa es 26,09896 N. Incorporar el peso del herraje con esas fuerzas es una equivalencia global; para esfuerzos locales debe aplicarse por separado en su posición.

Referencia y gravedad. El peso presente en ambos estados se cancela al comparar incrementos, si la respuesta de contactos es compatible. Se puede modelar la carga incremental sin gravedad o restar estados de referencia y carga. No contar el herraje dos veces ni atribuir un esfuerzo fijo a peso propio sin cálculo trazable.

La deriva, factor de galga, cableado, alineación, masa y módulo pueden contribuir, pero no se asignan porcentajes sin registros o calibración. La discrepancia permanece por explicar.

## 5. Conclusiones y trabajo necesario

El análisis del ZIP es aritméticamente correcto para su escenario de 5,073 kg. La revisión conserva ese caso y añade el de 5 kg porque la puesta a cero del herraje no se recuerda. El incremento medido supera la teoría nominal en aproximadamente 10–12 %.

El STEP actualizado es una mejora útil y mantiene los sólidos y la marca de galga verificados. Las corridas FEM históricas tienen cargas incompatibles, referencia distinta y exportaciones repetidas; no permiten declarar convergencia ni validar el esfuerzo de galga.

Para terminar: confirmar montaje, espesor, radios, centro y orientación de rejilla, posición de carga y adquisición; justificar contactos y apoyo; regenerar y resolver las mallas; exportar εyy y σyy en la misma rejilla; comprobar reacciones y momentos; aplicar un criterio de convergencia local previamente definido.

Se propone un umbral de variación del 2 % entre refinamientos, con al menos dos refinamientos sucesivos que lo cumplan, sujeto al criterio del curso. Es una propuesta de trabajo y no una exigencia atribuida al profesor ni una garantía de exactitud.

## Trazabilidad de la revisión

Se corrigieron grados/radianes, momento con la resultante, nombres sin definir y valores manuales de extremos. Las entradas antiguas remiten al mismo cálculo. El análisis acepta ventanas configurables, diagnostica CSV inválidos y guarda resultados con huella SHA-256 del original.

Se auditaron nueve HTML y se conservaron CSV y exportaciones históricas intactos. Pasaron ocho pruebas de cálculo, carga, promedio de rejilla, datos, ventanas y auditoría. El JSON de geometría conserva la comparación de los dos STEP. No se ejecutó FEM.

Este PDF se generó directamente desde los resultados verificados y se revisó visualmente. La fuente LaTeX se mantiene editable; su compilación en el editor integrado no pudo verificarse porque el compilador devolvió “Unable to find standard directories for platform”. Este PDF no se presenta como salida de ese compilador.

La cuenta GitHub conectada tiene acceso de lectura y carece de permiso de escritura en este repositorio. Se entrega copia corregida y parche; no se modificó main remoto.

Referencias técnicas:
- COMSOL: diferencia entre esfuerzo plano y deformación plana. (https://www.comsol.com/blogs/what-is-the-difference-between-plane-stress-and-plane-strain/)
- Autodesk: fuerzas remotas en simulación. (https://help.autodesk.com/cloudhelp/ENU/Fusion-Simulate/files/SIM-REMOTE-FORCE-CONCEPT.htm)

## Actualización: mallas de 10 y 15 mm

Los nuevos HTML distinguen las dos resoluciones. La exportación de 15 mm tiene recuentos y resultados distintos; queda corregida la repetición detectada en su archivo anterior. El usuario confirma que las capturas muestran Von Mises.

Malla | Nodos | Elementos | VM global máx. | VM en punto
15 mm | 48 735 | 24 301 | 20,722 MPa | 10,926 MPa
10 mm | 80 346 | 40 572 | 21,018 MPa | 10,984 MPa

Punto común: (17; 205; 29,997) mm. Diferencia = 0,058 MPa; variación respecto a la malla refinada = 0,058 / 10,984 × 100 = 0,528 %. Es una primera evidencia favorable de estabilidad local. Falta otro refinamiento para cerrar la convergencia y la lectura longitudinal promediada de la rejilla.


Capturas originales: izquierda, 10 mm; derecha, 15 mm. Valores de etiquetas; el tipo de resultado fue confirmado por el usuario.

Configuración aún pendiente de reconciliar: ambos HTML conservan dos fuerzas de 24,883 N, total vertical de 46,764 N, y = 707 mm y gravedad de 9,807 m/s². Las nuevas exportaciones no acreditan un cambio de esa carga ni del estado de referencia.

Comprobación orientativa: con A = 196 mm², ρ = 2,700×10⁶ kg/mm³ y la gravedad exportada, q = 0,0051898644 N/mm. En y = 205 mm, la flexión por las fuerzas da 10,636743 MPa; el peso de la viga hasta y = 746 mm añade 0,344123 MPa: suma ≈ 10,980866 MPa. Incluir el peso del herraje CAD idealizado añadiría ≈ 0,038069 MPa. La cercanía al resultado FEM apoya su plausibilidad para esta configuración, sin equivalencia exacta entre esfuerzo longitudinal y Von Mises.

El punto no coincide exactamente con el centro CAD y no representa el promedio de la rejilla. Los HTML corresponden a VIGA_FEM v25 y v26; coinciden sus materiales, cargas y contactos exportados, pero no se certifica identidad geométrica entre versiones.

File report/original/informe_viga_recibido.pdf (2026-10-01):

## Determinación del esfuerzo normal por flexión en una viga instrumentada: solución analítica, experimental y por elementos finitos

Brayan [PENDIENTE: apellidos] Samuel [PENDIENTE: apellidos] Universidad Pontificia Bolivariana, Medellín Elementos Finitos – Prof. Elkin Alonso Taborda Espinosa

6 de octubre de 2026

Resumen

Se determina el esfuerzo normal por flexión en la posición de una galga extensiométrica adherida a una viga tubular de aluminio 1100 en voladizo, sometida a una carga de 49,77 N. El problema se resuelve de tres formas: con la teoría de vigas de Euler–Bernoulli, con datos de laboratorio y con una simulación por elementos finitos (FEM). El valor analítico es 11,40 MPa (165,2 µε); el experimental, 12,55 MPa, difiere en 10,1 %. [PENDIENTE: resultado FEM, error FEM y conclusión tras completar la simulación].

## 1. Introducción

Una galga extensiométrica mide la deformación unitaria longitudinal de la superficie sobre la que está adherida, y el esfuerzo se obtiene con la ley de Hooke. En este trabajo se compara ese esfuerzo con el que predicen la mecánica de materiales y una simulación FEM, con el fin de validar los modelos y analizar las fuentes de error.

## 2. Datos del montaje

La viga es un tubo rectangular hueco de aluminio 1100, empotrado por medio de mordazas, con una pesa colgada de un tornillo cerca del extremo libre. La galga está adherida en la cara superior. Las coordenadas se toman del modelo CAD (VIGA_FEM.step), con el eje y a lo largo de la viga.

Tabla 1: Datos del montaje.

Parámetro | Símbolo | Valor
Módulo de elasticidad | E | 69 GPa
Masa de la pesa | mp | 5,000 kg
Masa del tornillo y arandelas | ma | 0,073 kg
Gravedad | g | 9,81 m/s
| | 2
Dimensiones exteriores de la sección | be × he | 70 mm×30 mm
Espesor de pared | t | 1 mm
Longitud total | L | 746 mm
Borde libre de la mordaza | ym | 141,83 mm
Centro de la galga (marca de 198 a 213 mm) | yg | 205,5 mm
Eje del tornillo (punto de carga) | yP | 711 mm
Rejilla sensible | – | 2,5 mm×10 mm

## 3. Parte 1: modelo analítico

### 3.1. Hipótesis

Se usa la teoría de Euler–Bernoulli con material elástico lineal, pequeñas deformaciones y sección prismática. La carga es estática y vertical. El peso propio se excluye porque la galga se puso en cero con la viga ya montada, de modo que el ensayo mide únicamente el incremento debido a la carga. En la cara superior, que es una superficie libre, el esfuerzo es uniaxial (σx), por lo que el esfuerzo de Von Mises coincide con |σx|.

### 3.2. Carga

m = mp + ma = 5,073 kg, | (1)
P = m g = 5,073 × 9,81 = 49,766 N. | (2)

La pesa cuelga de dos cuerdas simétricas inclinadas 20◦ respecto a la vertical (figura 1). La fuerza en cada cuerda es
F =

P
2 cos 20◦
= 26,48 N, | (3)

sus componentes horizontales se anulan y la suma de las verticales es exactamente P.

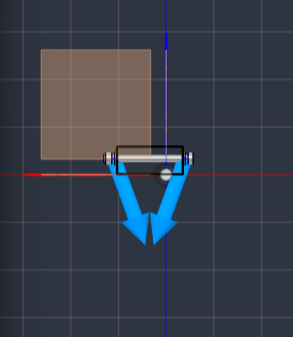
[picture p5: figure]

Figura 1: Cargas aplicadas en el modelo: dos fuerzas que parten de los extremos del tornillo y convergen hacia el nudo de la pesa.

### 3.3. Sección transversal

La sección es un rectángulo hueco de 70 mm×30 mm con espesor 1 mm. La viga se ensaya con la altura de 30 mm en vertical, así que la flexión ocurre alrededor del eje de menor inercia:

I =

beh

3
e − (be − 2t)(he − 2t)

3

12

=

70 · 30³ − 68 · 28³

12

= 33 105,3 mm⁴
, | (4)

c =

he
2
= 15 mm. | (5)

### 3.4. Momento flector, esfuerzo y deformación

El momento en la galga depende de su distancia al punto de carga:

a = yP − yg = 711 − 205,5 = 505,5 mm, | (6)
M(yg) = P a = 49,766 × 505,5 = 25 156,8 N mm, | (7)

σ =

M c
I

=

25156,8 × 15
33105,3
= 11,399 MPa, | (8)

ε =

σ
E

=

11,399
69000
= 165,2 µε. | (9)

Como el momento es lineal en y, el promedio sobre la rejilla coincide con el valor en su centro; en los extremos de la marca de galga (y = 198 y 213 mm) el esfuerzo es 11,57 MPa y 11,23 MPa.

### 3.5. Diagramas de fuerzas internas

El cortante es constante e igual a P entre la mordaza y la carga, y el momento flector decrece linealmente desde M0 = 28,33 N m en el borde de la mordaza hasta cero en el punto de carga (figura 2). La galga se ubica en una zona de momento alto, donde M = 25,16 N m.

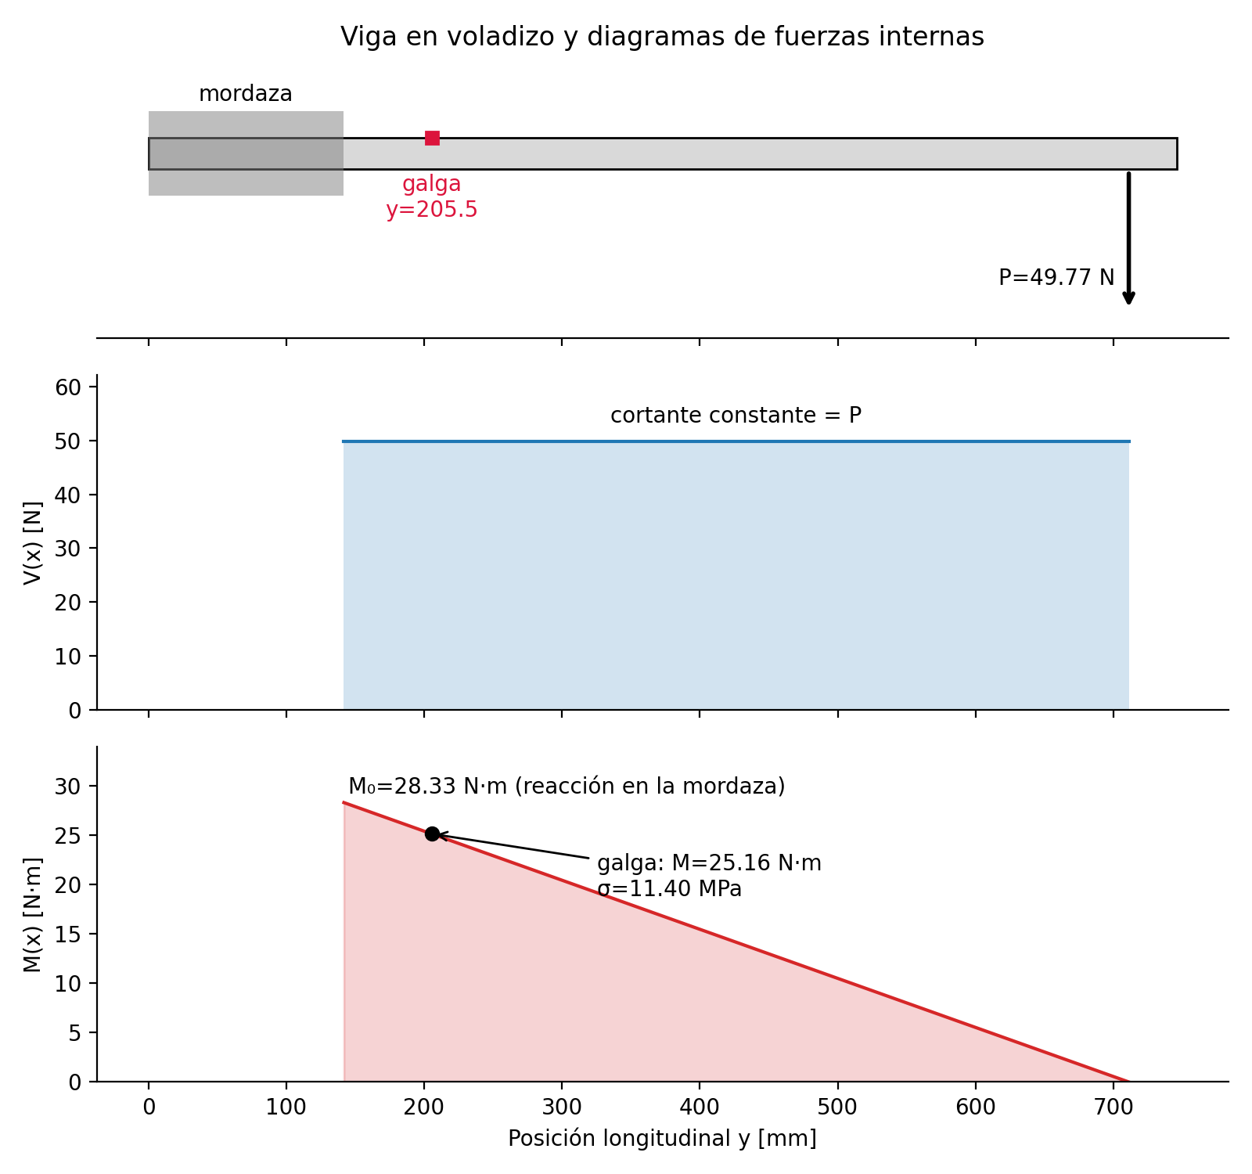
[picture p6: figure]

Figura 2: Esquema de la viga y diagramas de cortante V (y) y momento flector M(y).

## 4. Parte 2: resultados experimentales

El archivo del ensayo contiene 7 744 muestras a 100 Hz (77 s). La señal muestra una línea base, una rampa de carga, una meseta estable y la descarga (figura 3). Se promedió el strain en la meseta (t = 24 a 53 s, n = 2 901 muestras) y se le restó la línea base inmediatamente anterior a la carga (t = 11 a 16,5 s), porque la señal deriva de 0,4 µε al inicio a 3,5 µε antes de cargar.

Tabla 2: Resultados experimentales.

Magnitud | Sin línea base | Con línea base
Strain promedio en la meseta | 185,31 µε | 181,85 µε
Desviación estándar en la meseta | 0,86 µε
Esfuerzo σ = Eε | 12,79 MPa | 12,55 MPa

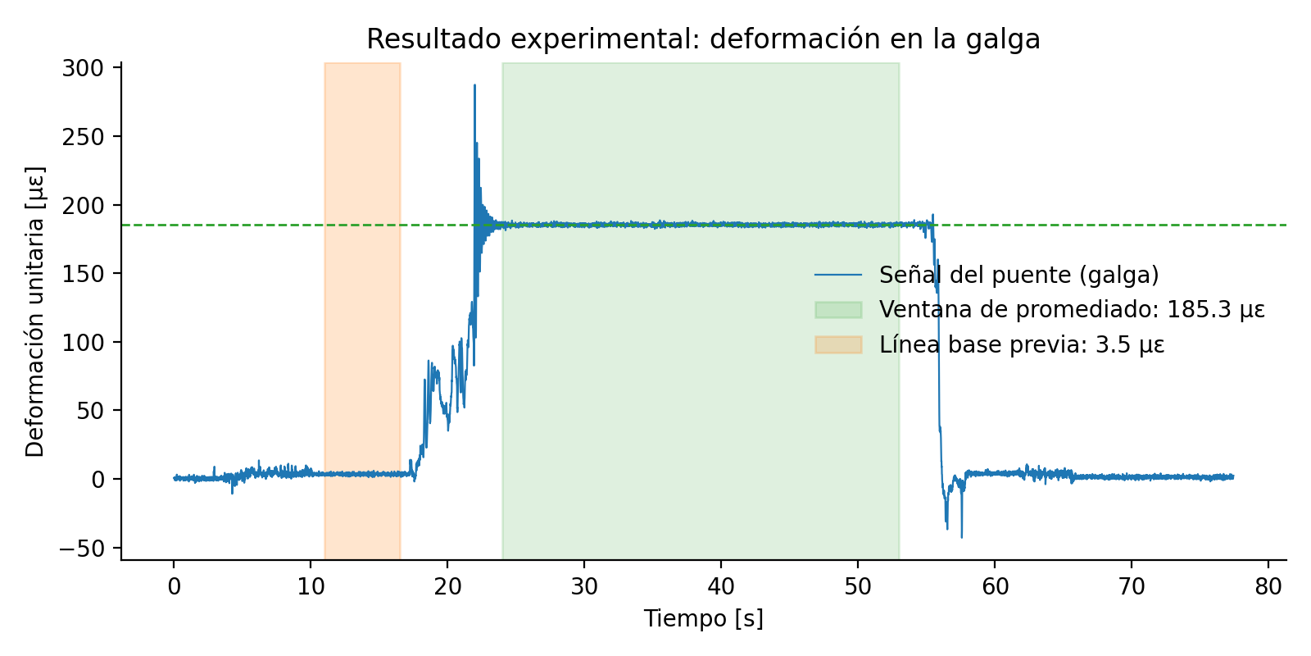
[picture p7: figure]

Figura 3: Deformación medida por la galga, con la ventana de promediado y la línea base.

## 5. Parte 3: simulación por elementos finitos

### 5.1. Modelo CAD

El modelo se construyó en Autodesk Fusion a partir de la geometría de la viga (tres sólidos contiguos), el tornillo, dos arandelas y una tuerca de cierre idealizada. La marca de galga de 5 mm×15 mm ocupa y = 198 a 213 mm en la cara superior, y el agujero de 8 mm está en y = 711 mm. [PENDIENTE: imágenes del modelo CAD desde la orientación del ensayo]

### 5.2. Condiciones de la simulación

Estático lineal con aluminio 1100 y E = 69 GPa; apoyo fijo en la zona de mordaza; dos fuerzas remotas de 26,48 N a 20◦ de la vertical aplicadas en y = 711 mm, sin gravedad (coherente con el tare de la galga). [PENDIENTE: confirmar apoyo, tipo de contactos y elemento]

### 5.3. Independencia de malla

Tabla 3: Estudio de convergencia (esfuerzo en el centro de la galga).

Tamaño de elemento [mm] | Nodos | σV M [MPa] | Variación [ %]
25 | [PENDIENTE: ] [PENDIENTE: ] | –
20 | [PENDIENTE: ] [PENDIENTE: ] [PENDIENTE: ]
15 | [PENDIENTE: ] [PENDIENTE: ] [PENDIENTE: ]
10 | [PENDIENTE: ] [PENDIENTE: ] [PENDIENTE: ]
5 | [PENDIENTE: ] [PENDIENTE: ] [PENDIENTE: ]

[PENDIENTE: gráfica de convergencia y valor final en la galga]

## 6. Parte 4: comparación y análisis

Tabla 4: Comparación de resultados (error respecto al analítico).

Método | σ [MPa] | Error [ %]
Analítico | 11,40 | –
Experimental (con línea base) | 12,55 | +10,1
Experimental (sin línea base) | 12,79 | +12,2
FEM | [PENDIENTE: ] [PENDIENTE: ]

### 6.1. Causas de las diferencias

Espesor de pared. La inercia depende casi linealmente del espesor: una variación de −0,05 mm eleva el esfuerzo teórico 4,8 %. Un espesor real de 0,90 mm bastaría para que el valor analítico llegara a 12,56 MPa, casi idéntico al experimental; conviene medirlo con calibrador. Los radios de esquina del perfil, ignorados en el modelo, también reducen I.
Galga y adquisición. El factor de galga configurado, la orientación de la galga, la resistencia de los cables y la deriva de la señal (3,5 µε antes de cargar y 1,3 µε después de descargar) aportan entre 1 y 2 %.
Geometría y carga. Un error de 3 mm en el brazo cambia el resultado solo 0,6 %, y la incer-tidumbre de la masa (aprox. 1 %) es menor que la diferencia observada.
Peso propio. Está excluido del ensayo (tare); en el FEM debe apagarse la gravedad, ya que aportaría 0,34 MPa (aprox. 3 %).
[PENDIENTE: causas específicas del FEM: tipo de elemento, malla en el espesor de 1 mm, condición de apoyo y contactos del tornillo]

## 7. Conclusiones

[PENDIENTE: redactar cuando esté el resultado FEM]

## A. Anexos

Archivos con los datos (Viga4SamuelBrayan.csv), modelo CAD en formato original (.f3d) y universal (.step), y archivos de la simulación FEM. Repositorio de trabajo: https://github.com/brayansan00/galgalab. (https://github.com/brayansan00/galgalab)

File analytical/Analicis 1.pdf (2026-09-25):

## Determinación del esfuerzo normal por flexión en una viga instrumentada

Brayan Smith Espinosa Villegas, samuel

Septiembre de 2026

Parte 1 – Modelo analítico

Análisis analítico de una viga instrumentada | Raizbius Villegas Vanegas

## Resumen

Se determina el esfuerzo normal por flexión esperado en la coordenada donde se encuentra la galga extensiométrica. La viga se modela como un tubo rectangular de aluminio 1100 sometido a una carga vertical producida por una masa de 5 kg, un tornillo y unas arandelas de 73 g. Se utiliza la orientación real de la sección, la posición medida de la carga y el centro de la rejilla sensible. El resultado es una magnitud de esfuerzo de 11,305 MPa y una deformación teórica de aproximadamente 163,8 ε.

## 1. Planteamiento del problema

La viga se encuentra empotrada mediante mordazas y soporta una carga vertical en su zona libre. La carga produce un momento flector que varía a lo largo de la viga. Debido a esto, el esfuerzo que se presenta en la galga depende de su posición longitudinal y no solamente de la longitud total de la viga.
El análisis se realiza con la teoría elemental de vigas de Euler–Bernoulli. Se considera comportamiento elástico lineal, sección prismática y pequeñas deformaciones. El peso propio se excluye del resultado principal porque se busca el incremento producido al aplicar la carga P, de forma coherente con el procesamiento experimental que resta la lectura inicial.

## 2. Datos del montaje

Cuadro 1: Datos utilizados en el cálculo analítico.
Parámetro | Símbolo | Valor
Material | – | Aluminio 1100
Módulo de elasticidad | E | 69 GPa
Masa de la pesa | mp | 5,000 kg
Masa del tornillo y arandelas | ma | 0,073 kg
Dimensiones exteriores | be × he | 70 mm×30 mm
Espesor | t | 1 mm
Longitud total | L | 746 mm
Coordenada de la carga | xP | 707 mm
Inicio del soporte de la galga | xs | 198 mm
Soporte modelado de la galga | Ls | 15 mm
Rejilla sensible | – | 2,5 mm×10 mm

## 3. Desarrollo analítico

### 3.1. Carga aplicada

La masa total que define la carga incluye la pesa, el tornillo y las arandelas:

m = mp + ma | (1)
= 5,000 kg + 0,073 kg | (2)
= 5,073 kg. | (3)

Utilizando g = 9,807 m/s
, el peso aplicado es:
P = mg | (4)

= (5,073 kg)(9,807 m/s

2
) | (5)
= 49,751 N. | (6)
Si la carga se representa mediante dos fuerzas simétricas inclinadas 20◦ | , la magnitud de cada
una debe ser
T =

P
2 cos 20◦
= 26,472 N, | (7)

de manera que las componentes horizontales se cancelen y las componentes verticales sumen P.

### 3.2. Geometría interior de la sección

La viga es un tubo rectangular. Al descontar una pared de 1 mm a cada lado, sus dimensiones interiores son:

bi = be − 2t = 70 − 2(1) = 68 mm, | (8)
hi = he − 2t = 30 − 2(1) = 28 mm. | (9)

### 3.3. Momento de inercia

Durante el ensayo, la dimensión vertical es 30 mm. Por ello, esta es la dimensión que aparece elevada al cubo en el momento de inercia asociado a la flexión producida por la carga vertical. Para una sección tubular rectangular:

I =

beh

3
e − bih

3
i
12
. | (10)

Sustituyendo los valores:

I =

70(30)³ − 68(28)³
12 | (11)

= 33 105,333 mm⁴
. | (12)

El eje neutro se encuentra en el centro de la sección. La distancia desde el eje neutro hasta la superficie instrumentada es:

c =

he
2

=

30
2
= 15 mm. | (13)

### 3.4. Coordenada representativa de la galga

El soporte exterior de la galga comienza aproximadamente en xs = 198 mm y mide 15 mm. Su centro se encuentra en:

xg = xs +

Ls
2 | (14)

= 198 +

15
2 | (15)
= 205,5 mm. | (16)

La rejilla sensible de 10 mm se encuentra centrada dentro del soporte, por lo que su centro coincide con xg. La lectura de la galga corresponde al promedio de deformación sobre esta rejilla.

### 3.5. Momento flector en la galga

El brazo de la carga respecto a la sección instrumentada es:

a = xP − xg | (17)
= 707 − 205.5 | (18)
= 501,5 mm. | (19)

Por tanto, el momento flector en la galga es:

Mg = P a | (20)
= (49,751 N)(501,5 mm) | (21)
= 24 950,082 N mm. | (22)

No se utiliza la longitud total de 746 mm como brazo porque la carga se aplica en la coordenada de 707 mm. Tampoco se utiliza la distancia entre el empotramiento y la carga, pues el esfuerzo solicitado corresponde a la sección donde está instalada la galga.

### 3.6. Esfuerzo normal por flexión

El esfuerzo normal en una fibra situada a una distancia c del eje neutro se calcula mediante:

σ =

M c
I
. | (23)

Para la superficie instrumentada:

σg =

(24 950,082 N mm)(15 mm)
33 105,333 mm⁴

(24)

= 11,305 N/mm²
(25)
= | 11,305 MPa | . | (26)

El signo depende de la cara instrumentada, del sentido definido para el momento y de la polaridad de conexión de la galga. La magnitud esperada es 11,305 MPa.

### 3.7. Deformación longitudinal esperada

En el intervalo elástico se aplica la ley de Hooke:

εg =

σg
E
. | (27)

Con E = 69 000 MPa:

εg =

11,305 MPa
69 000 MPa

(28)

= 1.6384 × 10⁻⁴
(29)
= | 163,8 ε | . | (30)

El módulo de elasticidad aparece en el cálculo de la deformación, pero no en la ecuación σ = M c/I. Bajo una carga conocida, el esfuerzo depende de la carga y de la geometría; el módulo E relaciona ese esfuerzo con la deformación resultante.

### 3.8. Promedio sobre la rejilla sensible

La rejilla de 10 mm se extiende aproximadamente desde 200,5 mm hasta 210,5 mm. En esos extremos se obtiene:

σ(200,5 mm) = 11,418 MPa, | (31)
σ(210,5 mm) = 11,192 MPa. | (32)

Como el momento cambia linealmente a lo largo de una viga prismática, el promedio de ambos extremos coincide con el esfuerzo en el centro:

σg =

11.418 + 11.192
2
= 11,305 MPa. | (33)

Por esta razón, evaluar el esfuerzo en el centro de la galga representa adecuadamente la lectura promedio de su rejilla sensible.

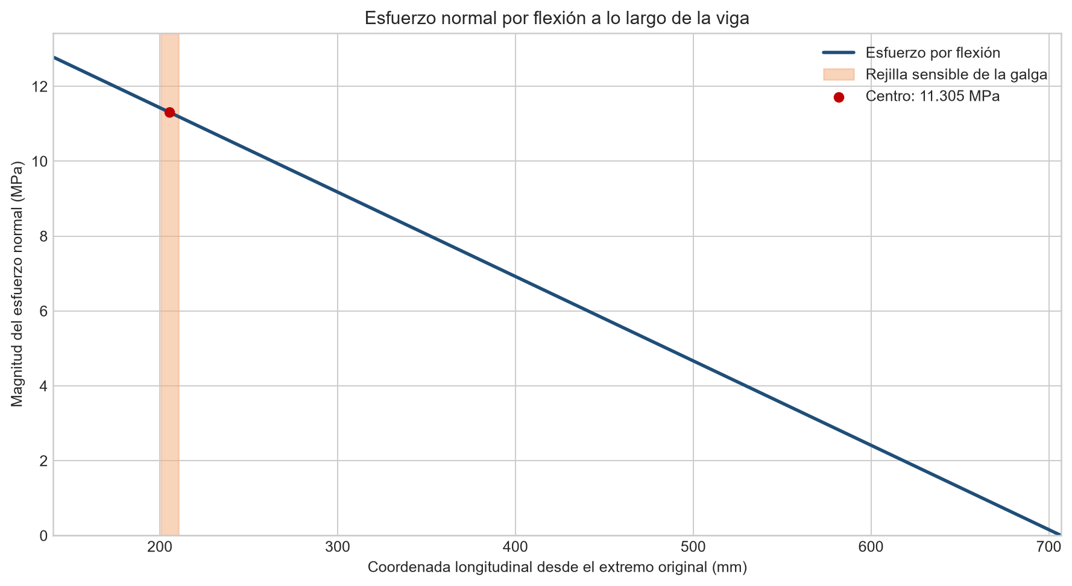
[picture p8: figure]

Figura 1: Variación de la magnitud del esfuerzo normal entre la salida del empotramiento y la coordenada de aplicación de la carga.

## 4. Resultado y conclusión

El cálculo analítico entrega los siguientes valores en la coordenada central de la galga:

|σg| = 11,305 MPa | , | |εg| = 163,8 ε | . | (34)

El tamaño de la rejilla no modifica de manera significativa el resultado, porque la variación del esfuerzo en sus 10 mm de longitud es pequeña y lineal. Estos valores constituyen la referencia analítica para comparar los resultados experimentales y los obtenidos mediante elementos finitos.

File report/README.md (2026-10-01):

# Informe en revisión

`informe_viga.tex` conserva la estructura del borrador recibido e incorpora las correcciones verificadas. Es autónomo: las figuras vectoriales están incluidas en la fuente, de modo que puede abrirse y compilarse sin archivos auxiliares. Las PNG equivalentes están en `../figures/` y se conservan copias de conveniencia en `figures/`.

El PDF y la fuente recibidos están en `original/`; sirven de historial y contienen afirmaciones corregidas en la versión actual. No presentarlos como informe vigente. La fecha de entrega del borrador se mantiene; la revisión está indicada dentro del documento.

`informe_viga_revisado.pdf` es la versión de lectura, generada directamente desde los resultados verificados y comprobada visualmente. La fuente LaTeX quedó abierta en el editor integrado, pero su compilador falló con `Unable to find standard directories for platform`. No se pudo verificar la compilación de la fuente y este PDF no se presenta como salida de ese compilador.

Los resultados FEM, la puesta a cero del herraje, las medidas físicas y la configuración de adquisición no están confirmados. El borrador no es una validación final.

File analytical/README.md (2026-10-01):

# Modelo analítico revisado

El programa vigente es `../python/analisis_viga.py`; `../python/analytical_model.py` permite ejecutar solo el cálculo. La entrada antigua `import math.py` remite al mismo modelo para evitar resultados incompatibles.

`Analicis 1.pdf` se conserva como desarrollo preliminar histórico; no es el informe revisado.

Se usa P·(yP − yg), no la tensión inclinada de una cuerda, para el momento de flexión global. Los ángulos se convierten a radianes. La coordenada longitudinal es y; la magnitud comparada es σyy bajo hipótesis uniaxial. La rejilla de 10 mm, si está centrada, tiene promedio igual al valor central porque el momento es lineal. Sus valores extremos se calculan a partir de las coordenadas y no se introducen manualmente.

El estado de referencia no se recuerda, por lo que se calculan 49,05 y 49,76613 N. La posición real de la rejilla, la orientación del perfil, el espesor, la carga y la aplicabilidad de Euler–Bernoulli cerca de la mordaza siguen sujetos a comprobación.

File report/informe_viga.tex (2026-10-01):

\documentclass[11pt,a4paper]{article}
\usepackage[utf8]{inputenc}
\usepackage[T1]{fontenc}
\IfFileExists{lmodern.sty}{\usepackage{lmodern}}{}
\usepackage[spanish,es-tabla]{babel}
\usepackage{amsmath,amssymb}
\usepackage{siunitx}
\usepackage{graphicx}
\usepackage{booktabs}
\usepackage{caption}
\usepackage{float}
\usepackage{xcolor}
\usepackage[a4paper,margin=2.5cm]{geometry}
\usepackage[hidelinks]{hyperref}
\sisetup{output-decimal-marker={,},group-separator={\,},locale=DE}
\DeclareSIUnit\microstrain{\text{\ensuremath{\mu\varepsilon}}}
\newcommand{\pend}[1]{\textcolor{red}{\textbf{[PENDIENTE: #1]}}}

\title{Determinaci\'on del esfuerzo normal por flexi\'on en una viga instrumentada:\\ soluci\'on anal\'itica, experimental y por elementos finitos}
\author{Brayan \pend{apellidos} \and Samuel \pend{apellidos}\\[2pt]
Universidad Pontificia Bolivariana, Medell\'in\\ Elementos Finitos -- Prof.\ Elkin Alonso Taborda Espinosa}
\date{6 de octubre de 2026}

\begin{document}
\maketitle
\begin{center}\small Borrador revisado el 30 de septiembre de 2026. Validación FEM pendiente.\end{center}

\begin{abstract}
Se compara la flexión de una viga tubular de aluminio 1100 mediante teoría de vigas, un ensayo con galga y exportaciones FEM preliminares. Con la geometría CAD, la teoría predice \SI{11.39852}{MPa} para una carga incremental de \SI{49.76613}{N}, o \SI{11.23449}{MPa} si el herraje ya estaba presente al poner la galga en cero y solo se añade la pesa de \SI{5}{kg}. El ensayo, corregido con la base previa, da \SI{181.85128}{\microstrain} y un esfuerzo equivalente uniaxial de \SI{12.54774}{MPa}. Las diferencias son respectivamente \SI{10.08}{\percent} y \SI{11.69}{\percent}. El estado de referencia no se recuerda y ambos escenarios se conservan. Las capturas nuevas de 15 y 10 mm dan Von Mises de 10.926 y 10.984 MPa en el mismo punto, con variación de 0.528\%. Las exportaciones FEM tienen cargas incompatibles y no permiten cerrar la validación ni la convergencia en la galga.
\end{abstract}

\section{Introducción}
Una galga mide deformación en su dirección sensible. La conversión $\sigma=E\varepsilon$ requiere un estado aproximadamente uniaxial, además de elasticidad lineal y una adquisición calibrada. El trabajo busca comparar la magnitud longitudinal en la misma región y para el mismo incremento de carga. El cálculo en Python reproduce teoría y tratamiento de datos; no constituye un cuarto método físico independiente.

\section{Datos del montaje}
La viga se representa como un tubo rectangular de aluminio 1100 empotrado por mordazas. En el CAD, $y$ es longitudinal, $z$ es vertical y la marca de galga está en la cara superior $z=\SI{30}{mm}$. Las dimensiones nominales y las coordenadas CAD no sustituyen las medidas del ensayo.
\begin{table}[H]\centering\small
\caption{Datos utilizados y condiciones por verificar.}
\begin{tabular}{@{}p{0.55\textwidth}p{0.37\textwidth}@{}}\toprule
Parámetro & Valor \\\midrule
Módulo adoptado $E$ & \SI{69}{GPa} \\
Pesa / herraje medido & \SI{5}{kg} / \SI{0.073}{kg} \\
Gravedad adoptada $g$ & \SI{9.81}{m/s^2} \\
Sección exterior / espesor nominal & $70\times30$ mm / \SI{1}{mm} \\
Longitud total & \SI{746}{mm} \\
Borde de división CAD próximo a mordaza & $y_m=\SI{141.83152}{mm}$ \\
Marca CAD / centro & $y=198$--213 mm / $y_g=\SI{205.5}{mm}$ \\
Eje de agujero CAD & $y_P\simeq\SI{711}{mm}$ \\
Rejilla sensible indicada & $2.5\times10$ mm; centro y dirección pendientes \\
Estado del herraje al poner en cero & Desconocido; conservar ambos casos \\
\bottomrule\end{tabular}\end{table}

\section{Parte 1: modelo analítico}
\subsection{Hipótesis y estado de referencia}
Se usa Euler--Bernoulli para flexión global: material elástico lineal, pequeñas deformaciones, sección nominal prismática y galga longitudinal. La altura vertical es \SI{30}{mm}; deben confirmarse la orientación, el espesor y el centro de la rejilla real. El centro CAD está a unos \SI{63.67}{mm} del borde de mordaza, por lo que los efectos locales del apoyo requieren revisión en FEM.

Se compara el incremento entre estado cargado y referencia. El peso de la viga se cancela si estaba presente en ambos estados. La condición del herraje no se recuerda: si se añadió después del cero, se incluye su peso; si ya estaba instalado, su peso se cancela. Si cambian contactos o pretensión, se debe justificar la aproximación incremental.

La componente longitudinal es $\sigma_{yy}$. Una cara libre de normal $z$ no implica por sí sola un estado uniaxial: pueden permanecer componentes en el plano. Para isotropía lineal,
\begin{equation}\varepsilon_{yy}=\frac{\sigma_{yy}-\nu(\sigma_{xx}+\sigma_{zz})}{E}.\end{equation}
En la aproximación uniaxial de viga, $\sigma_{yy}=E\varepsilon_{yy}$ y $\sigma_{VM}=|\sigma_{yy}|$; esa igualdad debe comprobarse antes de trasladarla al modelo sólido.

\subsection{Carga y fuerzas equivalentes}
\begin{align}
P_A&=(5+0.073)\,9.81=\SI{49.76613}{N},\\
P_B&=5\,9.81=\SI{49.05}{N}.
\end{align}
El escenario A añade herraje después del cero; B lo incluye en la referencia. Para representar una resultante vertical mediante dos fuerzas simétricas a $20^\circ$,
\begin{equation}F=\frac{P}{2\cos20^\circ};\qquad F_A=\SI{26.48000}{N},\quad F_B=\SI{26.09896}{N}.\end{equation}
La suma vertical es $P$ y las componentes horizontales se cancelan globalmente. La tensión física de cuerda que sostiene solo la pesa de \SI{5}{kg} corresponde a $F_B$. Distribuir además el peso del herraje entre ambas fuerzas es una equivalencia para flexión global, no una descripción exacta de cargas locales. Para el detalle del tornillo, su peso se aplica aparte en su posición y no se cuenta dos veces.

\subsection{Sección transversal}
\begin{align}
I_x&=\frac{b_e h_e^3-(b_e-2t)(h_e-2t)^3}{12}
=\frac{70\cdot30^3-68\cdot28^3}{12}=\SI{33105.33333}{mm^4},\\
c&=\frac{h_e}{2}=\SI{15}{mm}.
\end{align}
Se ignoran radios de esquina mientras no haya medidas suficientes para incluirlos.

\subsection{Momento, esfuerzo y promedio de rejilla}
\begin{align}
a&=y_P-y_g=711-205.5=\SI{505.5}{mm},\\
M_A(y_g)&=P_Aa=\SI{25156.778715}{N.mm},\\
\sigma_{yy,A}&=M_Ac/I_x=\SI{11.39852}{MPa},\\
\varepsilon_{yy,A}&=\sigma_{yy,A}/E=\SI{165.1959}{\microstrain},\\
\sigma_{yy,B}&=\SI{11.23449}{MPa},\qquad\varepsilon_{yy,B}=\SI{162.8187}{\microstrain}.
\end{align}
Si la rejilla de \SI{10}{mm} está centrada, ocupa $y=200.5$--210.5 mm. En A, sus esfuerzos extremos son \SI{11.51126}{MPa} y \SI{11.28577}{MPa}; su promedio coincide con el valor central por la linealidad del momento. La marca CAD de \SI{15}{mm} no es la rejilla sensible: sus extremos, $y=198$ y 213 mm, dan \SI{11.56763}{MPa} y \SI{11.22940}{MPa}.

\subsection{Diagramas de fuerzas internas}
Entre mordaza y carga, $|V|=P$ y $|M(y)|=P(y_P-y)$. Desde la carga hasta $y=\SI{746}{mm}$ ambos son cero en el modelo sin peso propio. Se muestran magnitudes; el signo depende de la convención de corte. En A, el momento de reacción en el borde CAD es aproximadamente \SI{28.33}{N.m}.
\begin{figure}[H]\centering
\setlength{\unitlength}{1mm}
\begin{picture}(140,107)
\put(22,88){\line(1,0){112}}
{\color{gray!35}\put(22,84){\rule{21.294mm}{8mm}}}
\put(52.853,88){\circle*{1.5}}
\put(52.853,95){\makebox(0,0){\scriptsize Galga}}
\put(128.745,88){\vector(0,-1){10}}
\put(128.745,95){\makebox(0,0){\scriptsize P}}
\put(22,25){\line(1,0){112}}\put(22,25){\line(0,1){32}}
\put(22,62){\line(1,0){112}}\put(22,62){\line(0,1){14}}
\put(6,41){\makebox(0,0){\rotatebox{90}{\small $|M|$ [N m]}}}
\put(6,69){\makebox(0,0){\small $|V|$ [N]}}
\put(78,12){\makebox(0,0){\small Coordenada longitudinal y [mm]}}
\put(22,6){\makebox(0,0)[l]{\scriptsize Rojo: 5,073 kg; azul: 5 kg. Magnitudes, sin convención de signo.}}
\put(22.000,25){\line(0,-1){1}}\put(22.000,21){\makebox(0,0){\scriptsize 0}}
\put(52.027,25){\line(0,-1){1}}\put(52.027,21){\makebox(0,0){\scriptsize 200}}
\put(82.054,25){\line(0,-1){1}}\put(82.054,21){\makebox(0,0){\scriptsize 400}}
\put(112.080,25){\line(0,-1){1}}\put(112.080,21){\makebox(0,0){\scriptsize 600}}
\put(134.000,25){\line(0,-1){1}}\put(134.000,21){\makebox(0,0){\scriptsize 746}}
\put(19,25.000){\makebox(0,0)[r]{\scriptsize 0}}
\put(19,35.667){\makebox(0,0)[r]{\scriptsize 10}}
\put(19,46.333){\makebox(0,0)[r]{\scriptsize 20}}
\put(19,57.000){\makebox(0,0)[r]{\scriptsize 30}}
\put(19,73.2){\makebox(0,0)[r]{\scriptsize 50}}
{\color{red!75!black}\linethickness{0.22mm}
\qbezier(43.294,73.612)(86.019,73.612)(128.745,73.612)
\qbezier(128.745,73.612)(128.745,67.806)(128.745,62.000)
\qbezier(128.745,62.000)(131.373,62.000)(134.000,62.000)
\qbezier(43.294,55.214)(86.019,40.107)(128.745,25.000)
\qbezier(128.745,25.000)(131.373,25.000)(134.000,25.000)
\put(52.853,51.834){\circle*{1.2}}
}
{\color{blue!70!black}\linethickness{0.22mm}
\qbezier(43.294,73.445)(86.019,73.445)(128.745,73.445)
\qbezier(128.745,73.445)(128.745,67.722)(128.745,62.000)
\qbezier(128.745,62.000)(131.373,62.000)(134.000,62.000)
\qbezier(43.294,54.779)(86.019,39.889)(128.745,25.000)
\qbezier(128.745,25.000)(131.373,25.000)(134.000,25.000)
\put(52.853,51.448){\circle*{1.2}}
}
\end{picture}
\caption{Flexión global para los dos estados de referencia; el tramo después de la carga también se incluye.}
\end{figure}

\section{Parte 2: resultados experimentales}
Se utiliza exclusivamente \texttt{Viga4SamuelBrayan.csv}, conservado sin modificación. Tiene 7\,744 muestras, pasos de \SI{0.01}{s} y duración de \SI{77.43}{s}. Se interpreta el canal exportado como deformación adimensional y se multiplica por $10^6$ para obtener microdeformación. \pend{configuración de adquisición, factor de galga, unidades y orientación real}

Las ventanas inclusivas son base previa de 11 a \SI{16.5}{s} ($n=551$) y meseta de 24 a \SI{53}{s} ($n=2\,901$). Se evita la rampa y se resta la media previa, dejando un incremento de \SI{181.85128}{\microstrain}.
\begin{table}[H]\centering\small
\caption{Resultado del procesamiento de la señal.}
\begin{tabular}{@{}lc@{}}\toprule
Magnitud & Valor \\\midrule
Media de meseta & \SI{185.31171}{\microstrain} \\
Media de base previa & \SI{3.46042}{\microstrain} \\
Incremento meseta menos base & \SI{181.85128}{\microstrain} \\
Desviación muestral en la meseta & \SI{0.85688}{\microstrain} \\
Esfuerzo equivalente sin corregir & \SI{12.78651}{MPa} \\
Esfuerzo equivalente con base previa & \SI{12.54774}{MPa} \\
\bottomrule\end{tabular}\end{table}
La desviación muestral caracteriza la dispersión temporal; no constituye la incertidumbre total ni justifica dividirla por $\sqrt n$ sin analizar la autocorrelación. Los esfuerzos equivalentes se calculan con $E=\SI{69}{GPa}$ bajo hipótesis uniaxial.
\begin{figure}[H]\centering
\setlength{\unitlength}{1mm}
\begin{picture}(140,71)
{\color{orange!18}\put(37.400,18){\rule{7.700mm}{44mm}}}
{\color{green!12}\put(55.600,18){\rule{40.600mm}{44mm}}}
\put(22,18){\line(1,0){112}}
\put(22,18){\line(0,1){44}}
\put(78,4){\makebox(0,0){\small Tiempo [s]}}
\put(3,41){\makebox(0,0){\rotatebox{90}{\small Deformación [$\mu\varepsilon$]}}}
\put(22.000,18){\line(0,-1){1}}\put(22.000,14){\makebox(0,0){\scriptsize 0}}
\put(36.000,18){\line(0,-1){1}}\put(36.000,14){\makebox(0,0){\scriptsize 10}}
\put(50.000,18){\line(0,-1){1}}\put(50.000,14){\makebox(0,0){\scriptsize 20}}
\put(64.000,18){\line(0,-1){1}}\put(64.000,14){\makebox(0,0){\scriptsize 30}}
\put(78.000,18){\line(0,-1){1}}\put(78.000,14){\makebox(0,0){\scriptsize 40}}
\put(92.000,18){\line(0,-1){1}}\put(92.000,14){\makebox(0,0){\scriptsize 50}}
\put(106.000,18){\line(0,-1){1}}\put(106.000,14){\makebox(0,0){\scriptsize 60}}
\put(120.000,18){\line(0,-1){1}}\put(120.000,14){\makebox(0,0){\scriptsize 70}}
\put(134.000,18){\line(0,-1){1}}\put(134.000,14){\makebox(0,0){\scriptsize 80}}
\put(22,24.453){\line(-1,0){1}}\put(19,24.453){\makebox(0,0)[r]{\scriptsize 0}}
\put(22,30.320){\line(-1,0){1}}\put(19,30.320){\makebox(0,0)[r]{\scriptsize 50}}
\put(22,36.187){\line(-1,0){1}}\put(19,36.187){\makebox(0,0)[r]{\scriptsize 100}}
\put(22,42.053){\line(-1,0){1}}\put(19,42.053){\makebox(0,0)[r]{\scriptsize 150}}
\put(22,47.920){\line(-1,0){1}}\put(19,47.920){\makebox(0,0)[r]{\scriptsize 200}}
\put(22,53.787){\line(-1,0){1}}\put(19,53.787){\makebox(0,0)[r]{\scriptsize 250}}
\put(22,59.653){\line(-1,0){1}}\put(19,59.653){\makebox(0,0)[r]{\scriptsize 300}}
{\color{blue!70!black}\linethickness{0.12mm}
\qbezier(22.000,24.516)(22.063,24.416)(22.126,24.317)
\qbezier(22.126,24.317)(22.133,24.462)(22.140,24.606)
\qbezier(22.140,24.606)(22.210,24.715)(22.280,24.823)
\qbezier(22.280,24.823)(22.413,24.608)(22.546,24.394)
\qbezier(22.546,24.394)(22.553,24.544)(22.560,24.694)
\qbezier(22.560,24.694)(22.581,24.495)(22.602,24.296)
\qbezier(22.602,24.296)(22.763,24.459)(22.924,24.621)
\qbezier(22.924,24.621)(22.938,24.462)(22.952,24.304)
\qbezier(22.952,24.304)(23.036,24.320)(23.120,24.336)
\qbezier(23.120,24.336)(23.246,24.480)(23.372,24.624)
\qbezier(23.372,24.624)(23.442,24.427)(23.512,24.231)
\qbezier(23.512,24.231)(23.526,24.520)(23.540,24.810)
\qbezier(23.540,24.810)(23.659,24.745)(23.778,24.680)
\qbezier(23.778,24.680)(23.855,24.512)(23.932,24.345)
\qbezier(23.932,24.345)(23.981,24.580)(24.030,24.814)
\qbezier(24.030,24.814)(24.086,24.458)(24.142,24.102)
\qbezier(24.142,24.102)(24.226,24.401)(24.310,24.699)
\qbezier(24.310,24.699)(24.338,24.484)(24.366,24.269)
\qbezier(24.366,24.269)(24.464,24.253)(24.562,24.237)
\qbezier(24.562,24.237)(24.590,24.434)(24.618,24.631)
\qbezier(24.618,24.631)(24.744,24.680)(24.870,24.729)
\qbezier(24.870,24.729)(24.961,24.531)(25.052,24.333)
\qbezier(25.052,24.333)(25.066,24.530)(25.080,24.728)
\qbezier(25.080,24.728)(25.171,24.504)(25.262,24.280)
\qbezier(25.262,24.280)(25.416,24.447)(25.570,24.615)
\qbezier(25.570,24.615)(25.598,24.475)(25.626,24.334)
\qbezier(25.626,24.334)(25.633,24.315)(25.640,24.295)
\qbezier(25.640,24.295)(25.759,24.466)(25.878,24.637)
\qbezier(25.878,24.637)(25.955,24.459)(26.032,24.280)
\qbezier(26.032,24.280)(26.081,24.893)(26.130,25.505)
\qbezier(26.130,25.505)(26.200,25.087)(26.270,24.669)
\qbezier(26.270,24.669)(26.277,24.498)(26.284,24.327)
\qbezier(26.284,24.327)(26.410,24.315)(26.536,24.302)
\qbezier(26.536,24.302)(26.627,24.469)(26.718,24.637)
\qbezier(26.718,24.637)(26.774,24.687)(26.830,24.737)
\qbezier(26.830,24.737)(26.837,24.563)(26.844,24.390)
\qbezier(26.844,24.390)(27.012,24.683)(27.180,24.976)
\qbezier(27.180,24.976)(27.243,24.569)(27.306,24.162)
\qbezier(27.306,24.162)(27.341,24.193)(27.376,24.223)
\qbezier(27.376,24.223)(27.439,24.542)(27.502,24.861)
\qbezier(27.502,24.861)(27.579,24.473)(27.656,24.086)
\qbezier(27.656,24.086)(27.747,24.500)(27.838,24.914)
\qbezier(27.838,24.914)(27.866,24.883)(27.894,24.853)
\qbezier(27.894,24.853)(27.922,24.014)(27.950,23.176)
\qbezier(27.950,23.176)(28.083,23.505)(28.216,23.834)
\qbezier(28.216,23.834)(28.265,24.387)(28.314,24.939)
\qbezier(28.314,24.939)(28.412,24.961)(28.510,24.982)
\qbezier(28.510,24.982)(28.573,24.669)(28.636,24.357)
\qbezier(28.636,24.357)(28.748,24.788)(28.860,25.218)
\qbezier(28.860,25.218)(28.923,24.737)(28.986,24.256)
\qbezier(28.986,24.256)(29.028,24.621)(29.070,24.986)
\qbezier(29.070,24.986)(29.126,24.554)(29.182,24.122)
\qbezier(29.182,24.122)(29.287,24.746)(29.392,25.371)
\qbezier(29.392,25.371)(29.469,24.922)(29.546,24.473)
\qbezier(29.546,24.473)(29.588,24.877)(29.630,25.280)
\qbezier(29.630,25.280)(29.693,24.948)(29.756,24.617)
\qbezier(29.756,24.617)(29.868,25.037)(29.980,25.457)
\qbezier(29.980,25.457)(30.043,25.137)(30.106,24.817)
\qbezier(30.106,24.817)(30.148,25.082)(30.190,25.347)
\qbezier(30.190,25.347)(30.253,24.938)(30.316,24.528)
\qbezier(30.316,24.528)(30.470,24.580)(30.624,24.631)
\qbezier(30.624,24.631)(30.638,24.941)(30.652,25.251)
\qbezier(30.652,25.251)(30.666,25.646)(30.680,26.040)
\qbezier(30.680,26.040)(30.813,25.391)(30.946,24.742)
\qbezier(30.946,24.742)(30.981,24.657)(31.016,24.572)
\qbezier(31.016,24.572)(31.093,24.884)(31.170,25.195)
\qbezier(31.170,25.195)(31.282,24.820)(31.394,24.444)
\qbezier(31.394,24.444)(31.415,24.745)(31.436,25.045)
\qbezier(31.436,25.045)(31.485,24.861)(31.534,24.677)
\qbezier(31.534,24.677)(31.632,25.063)(31.730,25.450)
\qbezier(31.730,25.450)(31.800,25.307)(31.870,25.165)
\qbezier(31.870,25.165)(31.947,24.885)(32.024,24.606)
\qbezier(32.024,24.606)(32.073,24.683)(32.122,24.761)
\qbezier(32.122,24.761)(32.206,25.079)(32.290,25.397)
\qbezier(32.290,25.397)(32.360,25.450)(32.430,25.504)
\qbezier(32.430,25.504)(32.472,25.165)(32.514,24.826)
\qbezier(32.514,24.826)(32.591,24.739)(32.668,24.652)
\qbezier(32.668,24.652)(32.780,25.021)(32.892,25.390)
\qbezier(32.892,25.390)(32.906,25.501)(32.920,25.612)
\qbezier(32.920,25.612)(32.962,25.070)(33.004,24.528)
\qbezier(33.004,24.528)(33.151,25.024)(33.298,25.521)
\qbezier(33.298,25.521)(33.361,25.068)(33.424,24.616)
\qbezier(33.424,24.616)(33.459,24.569)(33.494,24.522)
\qbezier(33.494,24.522)(33.592,25.138)(33.690,25.755)
\qbezier(33.690,25.755)(33.837,25.112)(33.984,24.469)
\qbezier(33.984,24.469)(34.005,24.893)(34.026,25.317)
\qbezier(34.026,25.317)(34.033,25.459)(34.040,25.600)
\qbezier(34.040,25.600)(34.138,25.106)(34.236,24.611)
\qbezier(34.236,24.611)(34.334,25.080)(34.432,25.548)
\qbezier(34.432,25.548)(34.460,25.080)(34.488,24.611)
\qbezier(34.488,24.611)(34.607,24.824)(34.726,25.037)
\qbezier(34.726,25.037)(34.740,24.846)(34.754,24.654)
\qbezier(34.754,24.654)(34.929,24.629)(35.104,24.603)
\qbezier(35.104,24.603)(35.125,24.914)(35.146,25.226)
\qbezier(35.146,25.226)(35.181,25.210)(35.216,25.194)
\qbezier(35.216,25.194)(35.286,24.936)(35.356,24.679)
\qbezier(35.356,24.679)(35.426,25.146)(35.496,25.613)
\qbezier(35.496,25.613)(35.524,25.181)(35.552,24.749)
\qbezier(35.552,24.749)(35.699,24.700)(35.846,24.652)
\qbezier(35.846,24.652)(35.888,24.970)(35.930,25.288)
\qbezier(35.930,25.288)(35.965,25.324)(36.000,25.359)
\qbezier(36.000,25.359)(36.084,25.005)(36.168,24.652)
\qbezier(36.168,24.652)(36.287,24.815)(36.406,24.978)
\qbezier(36.406,24.978)(36.455,24.864)(36.504,24.750)
\qbezier(36.504,24.750)(36.658,24.718)(36.812,24.686)
\qbezier(36.812,24.686)(36.819,24.899)(36.826,25.112)
\qbezier(36.826,25.112)(36.833,25.042)(36.840,24.973)
\qbezier(36.840,24.973)(36.917,24.855)(36.994,24.737)
\qbezier(36.994,24.737)(37.085,24.881)(37.176,25.025)
\qbezier(37.176,25.025)(37.260,24.885)(37.344,24.744)
\qbezier(37.344,24.744)(37.386,24.721)(37.428,24.697)
\qbezier(37.428,24.697)(37.547,24.843)(37.666,24.989)
\qbezier(37.666,24.989)(37.722,24.863)(37.778,24.738)
\qbezier(37.778,24.738)(37.827,24.884)(37.876,25.031)
\qbezier(37.876,25.031)(37.960,24.857)(38.044,24.683)
\qbezier(38.044,24.683)(38.051,24.884)(38.058,25.085)
\qbezier(38.058,25.085)(38.184,25.061)(38.310,25.038)
\qbezier(38.310,25.038)(38.373,24.881)(38.436,24.724)
\qbezier(38.436,24.724)(38.583,24.885)(38.730,25.046)
\qbezier(38.730,25.046)(38.751,24.930)(38.772,24.814)
\qbezier(38.772,24.814)(38.884,24.909)(38.996,25.004)
\qbezier(38.996,25.004)(39.024,24.866)(39.052,24.729)
\qbezier(39.052,24.729)(39.129,24.910)(39.206,25.092)
\qbezier(39.206,25.092)(39.234,24.877)(39.262,24.663)
\qbezier(39.262,24.663)(39.416,24.830)(39.570,24.997)
\qbezier(39.570,24.997)(39.577,24.837)(39.584,24.678)
\qbezier(39.584,24.678)(39.689,24.665)(39.794,24.652)
\qbezier(39.794,24.652)(39.822,24.839)(39.850,25.027)
\qbezier(39.850,25.027)(39.885,25.008)(39.920,24.988)
\qbezier(39.920,24.988)(39.927,24.818)(39.934,24.648)
\qbezier(39.934,24.648)(40.102,24.858)(40.270,25.068)
\qbezier(40.270,25.068)(40.284,24.898)(40.298,24.728)
\qbezier(40.298,24.728)(40.431,24.703)(40.564,24.678)
\qbezier(40.564,24.678)(40.641,24.819)(40.718,24.959)
\qbezier(40.718,24.959)(40.781,24.840)(40.844,24.721)
\qbezier(40.844,24.721)(40.872,24.892)(40.900,25.062)
\qbezier(40.900,25.062)(40.970,25.060)(41.040,25.058)
\qbezier(41.040,25.058)(41.047,24.854)(41.054,24.650)
\qbezier(41.054,24.650)(41.201,24.679)(41.348,24.708)
\qbezier(41.348,24.708)(41.369,24.872)(41.390,25.036)
\qbezier(41.390,25.036)(41.607,24.850)(41.824,24.665)
\qbezier(41.824,24.665)(41.845,24.854)(41.866,25.044)
\qbezier(41.866,25.044)(41.873,25.080)(41.880,25.116)
\qbezier(41.880,25.116)(41.894,24.856)(41.908,24.596)
\qbezier(41.908,24.596)(42.111,24.600)(42.314,24.605)
\qbezier(42.314,24.605)(42.370,24.881)(42.426,25.156)
\qbezier(42.426,25.156)(42.454,24.886)(42.482,24.617)
\qbezier(42.482,24.617)(42.489,24.790)(42.496,24.963)
\qbezier(42.496,24.963)(42.657,25.009)(42.818,25.055)
\qbezier(42.818,25.055)(42.853,24.866)(42.888,24.676)
\qbezier(42.888,24.676)(43.063,24.695)(43.238,24.714)
\qbezier(43.238,24.714)(43.252,24.846)(43.266,24.978)
\qbezier(43.266,24.978)(43.315,24.885)(43.364,24.792)
\qbezier(43.364,24.792)(43.392,24.935)(43.420,25.077)
\qbezier(43.420,25.077)(43.490,25.045)(43.560,25.013)
\qbezier(43.560,25.013)(43.616,24.852)(43.672,24.691)
\qbezier(43.672,24.691)(43.763,24.697)(43.854,24.703)
\qbezier(43.854,24.703)(43.882,24.859)(43.910,25.015)
\qbezier(43.910,25.015)(44.036,24.818)(44.162,24.621)
\qbezier(44.162,24.621)(44.211,24.852)(44.260,25.083)
\qbezier(44.260,25.083)(44.351,24.876)(44.442,24.670)
\qbezier(44.442,24.670)(44.491,24.883)(44.540,25.095)
\qbezier(44.540,25.095)(44.652,24.884)(44.764,24.672)
\qbezier(44.764,24.672)(44.827,24.889)(44.890,25.105)
\qbezier(44.890,25.105)(44.960,25.085)(45.030,25.065)
\qbezier(45.030,25.065)(45.121,24.843)(45.212,24.621)
\qbezier(45.212,24.621)(45.233,24.635)(45.254,24.649)
\qbezier(45.254,24.649)(45.282,24.848)(45.310,25.046)
\qbezier(45.310,25.046)(45.478,25.053)(45.646,25.059)
\qbezier(45.646,25.059)(45.709,24.884)(45.772,24.709)
\qbezier(45.772,24.709)(45.793,24.700)(45.814,24.691)
\qbezier(45.814,24.691)(45.940,24.888)(46.066,25.085)
\qbezier(46.066,25.085)(46.087,24.930)(46.108,24.775)
\qbezier(46.108,24.775)(46.129,25.430)(46.150,26.085)
\qbezier(46.150,26.085)(46.255,25.649)(46.360,25.214)
\qbezier(46.360,25.214)(46.472,24.721)(46.584,24.229)
\qbezier(46.584,24.229)(46.626,24.350)(46.668,24.471)
\qbezier(46.668,24.471)(46.759,25.178)(46.850,25.886)
\qbezier(46.850,25.886)(46.892,25.707)(46.934,25.528)
\qbezier(46.934,25.528)(47.060,26.044)(47.186,26.561)
\qbezier(47.186,26.561)(47.256,26.562)(47.326,26.563)
\qbezier(47.326,26.563)(47.368,26.984)(47.410,27.406)
\qbezier(47.410,27.406)(47.466,26.853)(47.522,26.301)
\qbezier(47.522,26.301)(47.585,29.633)(47.648,32.965)
\qbezier(47.648,32.965)(47.746,30.051)(47.844,27.138)
\qbezier(47.844,27.138)(47.935,30.827)(48.026,34.517)
\qbezier(48.026,34.517)(48.033,34.552)(48.040,34.586)
\qbezier(48.040,34.586)(48.117,31.898)(48.194,29.209)
\qbezier(48.194,29.209)(48.292,31.800)(48.390,34.392)
\qbezier(48.390,34.392)(48.474,33.190)(48.558,31.989)
\qbezier(48.558,31.989)(48.579,32.494)(48.600,33.000)
\qbezier(48.600,33.000)(48.635,33.534)(48.670,34.067)
\qbezier(48.670,34.067)(48.782,33.332)(48.894,32.597)
\qbezier(48.894,32.597)(48.943,33.173)(48.992,33.749)
\qbezier(48.992,33.749)(49.076,33.303)(49.160,32.858)
\qbezier(49.160,32.858)(49.272,31.763)(49.384,30.668)
\qbezier(49.384,30.668)(49.412,30.841)(49.440,31.015)
\qbezier(49.440,31.015)(49.559,30.519)(49.678,30.023)
\qbezier(49.678,30.023)(49.769,30.495)(49.860,30.968)
\qbezier(49.860,30.968)(49.923,30.242)(49.986,29.515)
\qbezier(49.986,29.515)(50.014,29.043)(50.042,28.572)
\qbezier(50.042,28.572)(50.154,29.692)(50.266,30.812)
\qbezier(50.266,30.812)(50.280,30.768)(50.294,30.725)
\qbezier(50.294,30.725)(50.413,33.281)(50.532,35.838)
\qbezier(50.532,35.838)(50.546,35.735)(50.560,35.632)
\qbezier(50.560,35.632)(50.693,34.898)(50.826,34.165)
\qbezier(50.826,34.165)(50.833,34.075)(50.840,33.986)
\qbezier(50.840,33.986)(50.917,32.075)(50.994,30.164)
\qbezier(50.994,30.164)(51.106,33.187)(51.218,36.209)
\qbezier(51.218,36.209)(51.281,34.026)(51.344,31.844)
\qbezier(51.344,31.844)(51.372,34.171)(51.400,36.499)
\qbezier(51.400,36.499)(51.512,33.671)(51.624,30.843)
\qbezier(51.624,30.843)(51.666,30.698)(51.708,30.553)
\qbezier(51.708,30.553)(51.799,32.155)(51.890,33.758)
\qbezier(51.890,33.758)(51.932,33.778)(51.974,33.798)
\qbezier(51.974,33.798)(52.093,35.987)(52.212,38.176)
\qbezier(52.212,38.176)(52.282,37.913)(52.352,37.650)
\qbezier(52.352,37.650)(52.415,38.630)(52.478,39.610)
\qbezier(52.478,39.610)(52.583,36.876)(52.688,34.143)
\qbezier(52.688,34.143)(52.737,46.164)(52.786,58.184)
\qbezier(52.786,58.184)(52.793,57.047)(52.800,55.910)
\qbezier(52.800,55.910)(52.842,46.226)(52.884,36.542)
\qbezier(52.884,36.542)(52.989,38.308)(53.094,40.075)
\qbezier(53.094,40.075)(53.143,45.971)(53.192,51.866)
\qbezier(53.192,51.866)(53.290,50.617)(53.388,49.368)
\qbezier(53.388,49.368)(53.437,46.580)(53.486,43.791)
\qbezier(53.486,43.791)(53.584,44.167)(53.682,44.543)
\qbezier(53.682,44.543)(53.731,46.139)(53.780,47.735)
\qbezier(53.780,47.735)(53.885,47.581)(53.990,47.426)
\qbezier(53.990,47.426)(54.032,46.341)(54.074,45.255)
\qbezier(54.074,45.255)(54.165,45.262)(54.256,45.268)
\qbezier(54.256,45.268)(54.298,46.079)(54.340,46.889)
\qbezier(54.340,46.889)(54.445,46.860)(54.550,46.830)
\qbezier(54.550,46.830)(54.606,46.212)(54.662,45.594)
\qbezier(54.662,45.594)(54.732,45.701)(54.802,45.807)
\qbezier(54.802,45.807)(54.865,46.201)(54.928,46.596)
\qbezier(54.928,46.596)(54.998,46.517)(55.068,46.439)
\qbezier(55.068,46.439)(55.124,46.132)(55.180,45.825)
\qbezier(55.180,45.825)(55.271,45.820)(55.362,45.816)
\qbezier(55.362,45.816)(55.425,46.132)(55.488,46.448)
\qbezier(55.488,46.448)(55.579,46.444)(55.670,46.439)
\qbezier(55.670,46.439)(55.698,46.170)(55.726,45.902)
\qbezier(55.726,45.902)(55.803,46.183)(55.880,46.464)
\qbezier(55.880,46.464)(55.901,46.093)(55.922,45.723)
\qbezier(55.922,45.723)(56.062,46.071)(56.202,46.419)
\qbezier(56.202,46.419)(56.314,46.158)(56.426,45.896)
\qbezier(56.426,45.896)(56.454,45.958)(56.482,46.020)
\qbezier(56.482,46.020)(56.531,46.291)(56.580,46.563)
\qbezier(56.580,46.563)(56.755,46.481)(56.930,46.400)
\qbezier(56.930,46.400)(56.951,46.179)(56.972,45.958)
\qbezier(56.972,45.958)(57.105,46.134)(57.238,46.311)
\qbezier(57.238,46.311)(57.245,46.128)(57.252,45.944)
\qbezier(57.252,45.944)(57.336,45.978)(57.420,46.012)
\qbezier(57.420,46.012)(57.434,46.218)(57.448,46.423)
\qbezier(57.448,46.423)(57.546,46.212)(57.644,46.002)
\qbezier(57.644,46.002)(57.721,46.202)(57.798,46.402)
\qbezier(57.798,46.402)(57.854,46.364)(57.910,46.326)
\qbezier(57.910,46.326)(57.987,46.193)(58.064,46.059)
\qbezier(58.064,46.059)(58.092,46.212)(58.120,46.365)
\qbezier(58.120,46.365)(58.155,46.194)(58.190,46.022)
\qbezier(58.190,46.022)(58.323,46.032)(58.456,46.043)
\qbezier(58.456,46.043)(58.554,46.192)(58.652,46.341)
\qbezier(58.652,46.341)(58.673,46.181)(58.694,46.021)
\qbezier(58.694,46.021)(58.708,46.181)(58.722,46.341)
\qbezier(58.722,46.341)(58.911,46.175)(59.100,46.009)
\qbezier(59.100,46.009)(59.121,46.164)(59.142,46.318)
\qbezier(59.142,46.318)(59.240,46.374)(59.338,46.429)
\qbezier(59.338,46.429)(59.422,46.213)(59.506,45.996)
\qbezier(59.506,45.996)(59.611,46.011)(59.716,46.026)
\qbezier(59.716,46.026)(59.744,46.196)(59.772,46.365)
\qbezier(59.772,46.365)(59.849,46.232)(59.926,46.100)
\qbezier(59.926,46.100)(59.954,46.234)(59.982,46.369)
\qbezier(59.982,46.369)(60.052,46.385)(60.122,46.402)
\qbezier(60.122,46.402)(60.199,46.212)(60.276,46.022)
\qbezier(60.276,46.022)(60.402,46.059)(60.528,46.096)
\qbezier(60.528,46.096)(60.563,46.277)(60.598,46.458)
\qbezier(60.598,46.458)(60.682,46.226)(60.766,45.994)
\qbezier(60.766,45.994)(60.822,46.254)(60.878,46.514)
\qbezier(60.878,46.514)(60.962,46.273)(61.046,46.032)
\qbezier(61.046,46.032)(61.116,46.251)(61.186,46.470)
\qbezier(61.186,46.470)(61.270,46.260)(61.354,46.051)
\qbezier(61.354,46.051)(61.361,46.212)(61.368,46.374)
\qbezier(61.368,46.374)(61.480,46.392)(61.592,46.409)
\qbezier(61.592,46.409)(61.669,46.196)(61.746,45.982)
\qbezier(61.746,45.982)(61.802,46.169)(61.858,46.356)
\qbezier(61.858,46.356)(61.907,46.181)(61.956,46.006)
\qbezier(61.956,46.006)(62.047,46.194)(62.138,46.383)
\qbezier(62.138,46.383)(62.222,46.175)(62.306,45.967)
\qbezier(62.306,45.967)(62.383,46.153)(62.460,46.339)
\qbezier(62.460,46.339)(62.488,46.188)(62.516,46.037)
\qbezier(62.516,46.037)(62.670,46.060)(62.824,46.084)
\qbezier(62.824,46.084)(62.845,46.202)(62.866,46.321)
\qbezier(62.866,46.321)(62.929,46.317)(62.992,46.312)
\qbezier(62.992,46.312)(62.999,46.155)(63.006,45.997)
\qbezier(63.006,45.997)(63.146,46.015)(63.286,46.032)
\qbezier(63.286,46.032)(63.307,46.169)(63.328,46.305)
\qbezier(63.328,46.305)(63.398,46.156)(63.468,46.006)
\qbezier(63.468,46.006)(63.510,46.178)(63.552,46.349)
\qbezier(63.552,46.349)(63.692,46.343)(63.832,46.337)
\qbezier(63.832,46.337)(63.909,46.155)(63.986,45.973)
\qbezier(63.986,45.973)(64.042,46.024)(64.098,46.076)
\qbezier(64.098,46.076)(64.112,46.206)(64.126,46.335)
\qbezier(64.126,46.335)(64.273,46.330)(64.420,46.325)
\qbezier(64.420,46.325)(64.434,46.142)(64.448,45.958)
\qbezier(64.448,45.958)(64.581,45.985)(64.714,46.011)
\qbezier(64.714,46.011)(64.770,46.173)(64.826,46.335)
\qbezier(64.826,46.335)(64.917,46.195)(65.008,46.056)
\qbezier(65.008,46.056)(65.015,46.209)(65.022,46.363)
\qbezier(65.022,46.363)(65.127,46.420)(65.232,46.478)
\qbezier(65.232,46.478)(65.253,46.203)(65.274,45.928)
\qbezier(65.274,45.928)(65.358,46.170)(65.442,46.413)
\qbezier(65.442,46.413)(65.470,46.197)(65.498,45.980)
\qbezier(65.498,45.980)(65.589,46.197)(65.680,46.413)
\qbezier(65.680,46.413)(65.792,46.217)(65.904,46.022)
\qbezier(65.904,46.022)(65.953,46.205)(66.002,46.389)
\qbezier(66.002,46.389)(66.030,46.196)(66.058,46.002)
\qbezier(66.058,46.002)(66.163,46.019)(66.268,46.035)
\qbezier(66.268,46.035)(66.359,46.179)(66.450,46.323)
\qbezier(66.450,46.323)(66.541,46.192)(66.632,46.061)
\qbezier(66.632,46.061)(66.667,46.280)(66.702,46.499)
\qbezier(66.702,46.499)(66.807,46.276)(66.912,46.053)
\qbezier(66.912,46.053)(66.961,46.240)(67.010,46.426)
\qbezier(67.010,46.426)(67.066,46.408)(67.122,46.390)
\qbezier(67.122,46.390)(67.220,46.207)(67.318,46.023)
\qbezier(67.318,46.023)(67.339,46.237)(67.360,46.452)
\qbezier(67.360,46.452)(67.444,46.298)(67.528,46.145)
\qbezier(67.528,46.145)(67.591,46.242)(67.654,46.339)
\qbezier(67.654,46.339)(67.696,46.177)(67.738,46.015)
\qbezier(67.738,46.015)(67.864,46.212)(67.990,46.409)
\qbezier(67.990,46.409)(68.074,46.181)(68.158,45.953)
\qbezier(68.158,45.953)(68.284,46.160)(68.410,46.368)
\qbezier(68.410,46.368)(68.424,46.213)(68.438,46.059)
\qbezier(68.438,46.059)(68.494,46.178)(68.550,46.298)
\qbezier(68.550,46.298)(68.557,46.190)(68.564,46.083)
\qbezier(68.564,46.083)(68.662,46.304)(68.760,46.525)
\qbezier(68.760,46.525)(68.844,46.259)(68.928,45.993)
\qbezier(68.928,45.993)(69.019,46.005)(69.110,46.018)
\qbezier(69.110,46.018)(69.187,46.219)(69.264,46.420)
\qbezier(69.264,46.420)(69.369,46.418)(69.474,46.415)
\qbezier(69.474,46.415)(69.481,46.207)(69.488,45.999)
\qbezier(69.488,45.999)(69.607,46.015)(69.726,46.032)
\qbezier(69.726,46.032)(69.740,46.179)(69.754,46.326)
\qbezier(69.754,46.326)(69.873,46.352)(69.992,46.377)
\qbezier(69.992,46.377)(70.034,46.148)(70.076,45.919)
\qbezier(70.076,45.919)(70.174,46.123)(70.272,46.327)
\qbezier(70.272,46.327)(70.279,46.150)(70.286,45.973)
\qbezier(70.286,45.973)(70.363,46.036)(70.440,46.099)
\qbezier(70.440,46.099)(70.517,46.176)(70.594,46.254)
\qbezier(70.594,46.254)(70.720,46.125)(70.846,45.997)
\qbezier(70.846,45.997)(70.895,46.215)(70.944,46.433)
\qbezier(70.944,46.433)(71.014,46.415)(71.084,46.397)
\qbezier(71.084,46.397)(71.140,46.120)(71.196,45.843)
\qbezier(71.196,45.843)(71.301,45.878)(71.406,45.913)
\qbezier(71.406,45.913)(71.469,46.135)(71.532,46.358)
\qbezier(71.532,46.358)(71.623,46.470)(71.714,46.583)
\qbezier(71.714,46.583)(71.735,46.257)(71.756,45.930)
\qbezier(71.756,45.930)(71.798,45.946)(71.840,45.962)
\qbezier(71.840,45.962)(71.847,46.171)(71.854,46.380)
\qbezier(71.854,46.380)(71.994,46.454)(72.134,46.527)
\qbezier(72.134,46.527)(72.197,46.243)(72.260,45.960)
\qbezier(72.260,45.960)(72.386,46.161)(72.512,46.363)
\qbezier(72.512,46.363)(72.589,46.225)(72.666,46.086)
\qbezier(72.666,46.086)(72.708,46.037)(72.750,45.987)
\qbezier(72.750,45.987)(72.827,46.177)(72.904,46.368)
\qbezier(72.904,46.368)(72.995,46.210)(73.086,46.053)
\qbezier(73.086,46.053)(73.135,46.239)(73.184,46.424)
\qbezier(73.184,46.424)(73.240,46.193)(73.296,45.962)
\qbezier(73.296,45.962)(73.366,46.159)(73.436,46.355)
\qbezier(73.436,46.355)(73.597,46.182)(73.758,46.009)
\qbezier(73.758,46.009)(73.765,46.194)(73.772,46.378)
\qbezier(73.772,46.378)(73.863,46.201)(73.954,46.024)
\qbezier(73.954,46.024)(73.989,46.202)(74.024,46.380)
\qbezier(74.024,46.380)(74.122,46.205)(74.220,46.030)
\qbezier(74.220,46.030)(74.283,46.240)(74.346,46.450)
\qbezier(74.346,46.450)(74.402,46.242)(74.458,46.035)
\qbezier(74.458,46.035)(74.535,46.237)(74.612,46.439)
\qbezier(74.612,46.439)(74.731,46.253)(74.850,46.067)
\qbezier(74.850,46.067)(74.878,46.235)(74.906,46.402)
\qbezier(74.906,46.402)(74.962,46.239)(75.018,46.076)
\qbezier(75.018,46.076)(75.025,46.312)(75.032,46.549)
\qbezier(75.032,46.549)(75.130,46.304)(75.228,46.058)
\qbezier(75.228,46.058)(75.270,46.241)(75.312,46.424)
\qbezier(75.312,46.424)(75.438,46.391)(75.564,46.357)
\qbezier(75.564,46.357)(75.606,46.209)(75.648,46.060)
\qbezier(75.648,46.060)(75.739,46.056)(75.830,46.053)
\qbezier(75.830,46.053)(75.858,46.190)(75.886,46.328)
\qbezier(75.886,46.328)(75.991,46.345)(76.096,46.361)
\qbezier(76.096,46.361)(76.117,46.181)(76.138,46.000)
\qbezier(76.138,46.000)(76.236,46.041)(76.334,46.081)
\qbezier(76.334,46.081)(76.418,46.192)(76.502,46.303)
\qbezier(76.502,46.303)(76.628,46.176)(76.754,46.049)
\qbezier(76.754,46.049)(76.810,46.215)(76.866,46.382)
\qbezier(76.866,46.382)(76.971,46.379)(77.076,46.376)
\qbezier(77.076,46.376)(77.083,46.217)(77.090,46.059)
\qbezier(77.090,46.059)(77.146,46.293)(77.202,46.528)
\qbezier(77.202,46.528)(77.216,46.311)(77.230,46.094)
\qbezier(77.230,46.094)(77.356,46.209)(77.482,46.325)
\qbezier(77.482,46.325)(77.545,46.145)(77.608,45.965)
\qbezier(77.608,45.965)(77.664,46.016)(77.720,46.067)
\qbezier(77.720,46.067)(77.818,46.239)(77.916,46.410)
\qbezier(77.916,46.410)(77.993,46.250)(78.070,46.091)
\qbezier(78.070,46.091)(78.140,46.280)(78.210,46.468)
\qbezier(78.210,46.468)(78.280,46.278)(78.350,46.088)
\qbezier(78.350,46.088)(78.371,46.244)(78.392,46.400)
\qbezier(78.392,46.400)(78.490,46.213)(78.588,46.027)
\qbezier(78.588,46.027)(78.630,46.220)(78.672,46.412)
\qbezier(78.672,46.412)(78.770,46.228)(78.868,46.045)
\qbezier(78.868,46.045)(78.945,46.220)(79.022,46.394)
\qbezier(79.022,46.394)(79.120,46.208)(79.218,46.022)
\qbezier(79.218,46.022)(79.295,46.217)(79.372,46.412)
\qbezier(79.372,46.412)(79.386,46.248)(79.400,46.085)
\qbezier(79.400,46.085)(79.491,46.244)(79.582,46.404)
\qbezier(79.582,46.404)(79.666,46.197)(79.750,45.989)
\qbezier(79.750,45.989)(79.813,46.206)(79.876,46.423)
\qbezier(79.876,46.423)(79.967,46.194)(80.058,45.964)
\qbezier(80.058,45.964)(80.072,46.169)(80.086,46.374)
\qbezier(80.086,46.374)(80.233,46.167)(80.380,45.960)
\qbezier(80.380,45.960)(80.408,46.140)(80.436,46.320)
\qbezier(80.436,46.320)(80.555,46.344)(80.674,46.368)
\qbezier(80.674,46.368)(80.716,46.192)(80.758,46.015)
\qbezier(80.758,46.015)(80.779,46.001)(80.800,45.986)
\qbezier(80.800,45.986)(80.898,46.166)(80.996,46.347)
\qbezier(80.996,46.347)(81.094,46.166)(81.192,45.985)
\qbezier(81.192,45.985)(81.248,46.156)(81.304,46.327)
\qbezier(81.304,46.327)(81.367,46.181)(81.430,46.036)
\qbezier(81.430,46.036)(81.493,46.183)(81.556,46.331)
\qbezier(81.556,46.331)(81.696,46.375)(81.836,46.419)
\qbezier(81.836,46.419)(81.843,46.186)(81.850,45.953)
\qbezier(81.850,45.953)(81.955,46.015)(82.060,46.078)
\qbezier(82.060,46.078)(82.081,46.194)(82.102,46.311)
\qbezier(82.102,46.311)(82.151,46.132)(82.200,45.953)
\qbezier(82.200,45.953)(82.256,46.150)(82.312,46.346)
\qbezier(82.312,46.346)(82.410,46.149)(82.508,45.952)
\qbezier(82.508,45.952)(82.536,46.131)(82.564,46.310)
\qbezier(82.564,46.310)(82.662,46.190)(82.760,46.070)
\qbezier(82.760,46.070)(82.823,46.222)(82.886,46.374)
\qbezier(82.886,46.374)(82.963,46.191)(83.040,46.008)
\qbezier(83.040,46.008)(83.138,46.202)(83.236,46.396)
\qbezier(83.236,46.396)(83.327,46.202)(83.418,46.007)
\qbezier(83.418,46.007)(83.467,46.165)(83.516,46.323)
\qbezier(83.516,46.323)(83.572,46.177)(83.628,46.032)
\qbezier(83.628,46.032)(83.747,46.207)(83.866,46.382)
\qbezier(83.866,46.382)(83.992,46.171)(84.118,45.961)
\qbezier(84.118,45.961)(84.132,46.151)(84.146,46.341)
\qbezier(84.146,46.341)(84.202,46.174)(84.258,46.007)
\qbezier(84.258,46.007)(84.279,46.202)(84.300,46.396)
\qbezier(84.300,46.396)(84.391,46.408)(84.482,46.419)
\qbezier(84.482,46.419)(84.531,46.220)(84.580,46.020)
\qbezier(84.580,46.020)(84.664,46.025)(84.748,46.030)
\qbezier(84.748,46.030)(84.811,46.182)(84.874,46.335)
\qbezier(84.874,46.335)(85.028,46.180)(85.182,46.024)
\qbezier(85.182,46.024)(85.203,46.176)(85.224,46.328)
\qbezier(85.224,46.328)(85.259,46.371)(85.294,46.413)
\qbezier(85.294,46.413)(85.336,46.202)(85.378,45.990)
\qbezier(85.378,45.990)(85.546,46.175)(85.714,46.361)
\qbezier(85.714,46.361)(85.721,46.208)(85.728,46.055)
\qbezier(85.728,46.055)(85.833,46.044)(85.938,46.032)
\qbezier(85.938,46.032)(86.001,46.186)(86.064,46.339)
\qbezier(86.064,46.339)(86.120,46.334)(86.176,46.329)
\qbezier(86.176,46.329)(86.190,46.171)(86.204,46.014)
\qbezier(86.204,46.014)(86.323,46.181)(86.442,46.349)
\qbezier(86.442,46.349)(86.456,46.146)(86.470,45.944)
\qbezier(86.470,45.944)(86.638,46.133)(86.806,46.323)
\qbezier(86.806,46.323)(86.813,46.209)(86.820,46.096)
\qbezier(86.820,46.096)(86.925,46.057)(87.030,46.018)
\qbezier(87.030,46.018)(87.093,46.181)(87.156,46.345)
\qbezier(87.156,46.345)(87.198,46.363)(87.240,46.382)
\qbezier(87.240,46.382)(87.289,46.204)(87.338,46.025)
\qbezier(87.338,46.025)(87.534,46.017)(87.730,46.009)
\qbezier(87.730,46.009)(87.737,46.188)(87.744,46.368)
\qbezier(87.744,46.368)(87.842,46.144)(87.940,45.920)
\qbezier(87.940,45.920)(88.003,46.189)(88.066,46.458)
\qbezier(88.066,46.458)(88.143,46.218)(88.220,45.978)
\qbezier(88.220,45.978)(88.283,46.153)(88.346,46.328)
\qbezier(88.346,46.328)(88.374,46.356)(88.402,46.385)
\qbezier(88.402,46.385)(88.430,46.182)(88.458,45.979)
\qbezier(88.458,45.979)(88.577,46.185)(88.696,46.392)
\qbezier(88.696,46.392)(88.787,46.221)(88.878,46.050)
\qbezier(88.878,46.050)(88.948,46.031)(89.018,46.013)
\qbezier(89.018,46.013)(89.060,46.202)(89.102,46.392)
\qbezier(89.102,46.392)(89.186,46.222)(89.270,46.053)
\qbezier(89.270,46.053)(89.361,46.264)(89.452,46.474)
\qbezier(89.452,46.474)(89.487,46.441)(89.522,46.408)
\qbezier(89.522,46.408)(89.606,46.234)(89.690,46.060)
\qbezier(89.690,46.060)(89.760,46.046)(89.830,46.032)
\qbezier(89.830,46.032)(89.886,46.233)(89.942,46.435)
\qbezier(89.942,46.435)(89.991,46.230)(90.040,46.025)
\qbezier(90.040,46.025)(90.096,46.181)(90.152,46.337)
\qbezier(90.152,46.337)(90.334,46.385)(90.516,46.434)
\qbezier(90.516,46.434)(90.537,46.249)(90.558,46.065)
\qbezier(90.558,46.065)(90.579,46.054)(90.600,46.044)
\qbezier(90.600,46.044)(90.663,46.194)(90.726,46.343)
\qbezier(90.726,46.343)(90.852,46.190)(90.978,46.037)
\qbezier(90.978,46.037)(91.055,46.187)(91.132,46.337)
\qbezier(91.132,46.337)(91.202,46.343)(91.272,46.349)
\qbezier(91.272,46.349)(91.328,46.211)(91.384,46.074)
\qbezier(91.384,46.074)(91.447,46.064)(91.510,46.055)
\qbezier(91.510,46.055)(91.517,46.210)(91.524,46.365)
\qbezier(91.524,46.365)(91.622,46.205)(91.720,46.044)
\qbezier(91.720,46.044)(91.853,46.205)(91.986,46.365)
\qbezier(91.986,46.365)(92.021,46.147)(92.056,45.929)
\qbezier(92.056,45.929)(92.084,46.182)(92.112,46.436)
\qbezier(92.112,46.436)(92.196,46.227)(92.280,46.018)
\qbezier(92.280,46.018)(92.287,46.251)(92.294,46.485)
\qbezier(92.294,46.485)(92.469,46.475)(92.644,46.464)
\qbezier(92.644,46.464)(92.672,46.232)(92.700,45.999)
\qbezier(92.700,45.999)(92.798,45.969)(92.896,45.938)
\qbezier(92.896,45.938)(92.994,46.145)(93.092,46.351)
\qbezier(93.092,46.351)(93.169,46.176)(93.246,46.000)
\qbezier(93.246,46.000)(93.295,46.220)(93.344,46.439)
\qbezier(93.344,46.439)(93.379,46.449)(93.414,46.459)
\qbezier(93.414,46.459)(93.470,46.200)(93.526,45.942)
\qbezier(93.526,45.942)(93.638,45.976)(93.750,46.010)
\qbezier(93.750,46.010)(93.792,46.173)(93.834,46.335)
\qbezier(93.834,46.335)(93.897,46.168)(93.960,46.001)
\qbezier(93.960,46.001)(94.016,46.182)(94.072,46.364)
\qbezier(94.072,46.364)(94.254,46.187)(94.436,46.010)
\qbezier(94.436,46.010)(94.450,46.205)(94.464,46.399)
\qbezier(94.464,46.399)(94.555,46.212)(94.646,46.024)
\qbezier(94.646,46.024)(94.660,46.215)(94.674,46.405)
\qbezier(94.674,46.405)(94.807,46.260)(94.940,46.115)
\qbezier(94.940,46.115)(94.982,46.212)(95.024,46.310)
\qbezier(95.024,46.310)(95.150,46.126)(95.276,45.942)
\qbezier(95.276,45.942)(95.290,46.161)(95.304,46.380)
\qbezier(95.304,46.380)(95.346,46.370)(95.388,46.359)
\qbezier(95.388,46.359)(95.493,46.186)(95.598,46.012)
\qbezier(95.598,46.012)(95.661,46.189)(95.724,46.366)
\qbezier(95.724,46.366)(95.731,46.213)(95.738,46.060)
\qbezier(95.738,46.060)(95.836,46.250)(95.934,46.441)
\qbezier(95.934,46.441)(96.025,46.266)(96.116,46.092)
\qbezier(96.116,46.092)(96.200,46.255)(96.284,46.419)
\qbezier(96.284,46.419)(96.361,46.198)(96.438,45.978)
\qbezier(96.438,45.978)(96.459,46.198)(96.480,46.419)
\qbezier(96.480,46.419)(96.564,46.243)(96.648,46.067)
\qbezier(96.648,46.067)(96.774,46.228)(96.900,46.389)
\qbezier(96.900,46.389)(96.949,46.172)(96.998,45.955)
\qbezier(96.998,45.955)(97.089,46.192)(97.180,46.429)
\qbezier(97.180,46.429)(97.243,46.242)(97.306,46.055)
\qbezier(97.306,46.055)(97.313,46.084)(97.320,46.113)
\qbezier(97.320,46.113)(97.390,46.270)(97.460,46.427)
\qbezier(97.460,46.427)(97.558,46.184)(97.656,45.941)
\qbezier(97.656,45.941)(97.698,46.273)(97.740,46.606)
\qbezier(97.740,46.606)(97.901,46.344)(98.062,46.082)
\qbezier(98.062,46.082)(98.076,46.251)(98.090,46.420)
\qbezier(98.090,46.420)(98.195,46.454)(98.300,46.487)
\qbezier(98.300,46.487)(98.328,46.159)(98.356,45.830)
\qbezier(98.356,45.830)(98.468,46.156)(98.580,46.481)
\qbezier(98.580,46.481)(98.636,46.027)(98.692,45.572)
\qbezier(98.692,45.572)(98.790,45.320)(98.888,45.068)
\qbezier(98.888,45.068)(98.937,45.736)(98.986,46.403)
\qbezier(98.986,46.403)(99.014,46.497)(99.042,46.590)
\qbezier(99.042,46.590)(99.140,46.226)(99.238,45.861)
\qbezier(99.238,45.861)(99.294,46.139)(99.350,46.417)
\qbezier(99.350,46.417)(99.448,45.577)(99.546,44.737)
\qbezier(99.546,44.737)(99.602,45.914)(99.658,47.092)
\qbezier(99.658,47.092)(99.714,44.933)(99.770,42.774)
\qbezier(99.770,42.774)(99.805,43.614)(99.840,44.453)
\qbezier(99.840,44.453)(99.945,42.409)(100.050,40.365)
\qbezier(100.050,40.365)(100.106,41.799)(100.162,43.232)
\qbezier(100.162,43.232)(100.253,35.885)(100.344,28.538)
\qbezier(100.344,28.538)(100.372,28.679)(100.400,28.821)
\qbezier(100.400,28.821)(100.533,26.256)(100.666,23.690)
\qbezier(100.666,23.690)(100.673,23.727)(100.680,23.763)
\qbezier(100.680,23.763)(100.813,22.361)(100.946,20.959)
\qbezier(100.946,20.959)(101.037,20.548)(101.128,20.136)
\qbezier(101.128,20.136)(101.177,21.674)(101.226,23.212)
\qbezier(101.226,23.212)(101.247,23.172)(101.268,23.132)
\qbezier(101.268,23.132)(101.366,23.534)(101.464,23.936)
\qbezier(101.464,23.936)(101.499,23.645)(101.534,23.355)
\qbezier(101.534,23.355)(101.653,23.952)(101.772,24.550)
\qbezier(101.772,24.550)(101.842,24.656)(101.912,24.762)
\qbezier(101.912,24.762)(101.975,24.525)(102.038,24.289)
\qbezier(102.038,24.289)(102.080,24.345)(102.122,24.401)
\qbezier(102.122,24.401)(102.199,24.080)(102.276,23.760)
\qbezier(102.276,23.760)(102.346,24.108)(102.416,24.457)
\qbezier(102.416,24.457)(102.514,21.937)(102.612,19.416)
\qbezier(102.612,19.416)(102.626,20.828)(102.640,22.239)
\qbezier(102.640,22.239)(102.661,23.271)(102.682,24.302)
\qbezier(102.682,24.302)(102.801,24.033)(102.920,23.764)
\qbezier(102.920,23.764)(102.983,24.402)(103.046,25.040)
\qbezier(103.046,25.040)(103.130,24.796)(103.214,24.551)
\qbezier(103.214,24.551)(103.277,24.875)(103.340,25.200)
\qbezier(103.340,25.200)(103.438,24.916)(103.536,24.633)
\qbezier(103.536,24.633)(103.564,24.863)(103.592,25.093)
\qbezier(103.592,25.093)(103.732,25.091)(103.872,25.089)
\qbezier(103.872,25.089)(103.949,24.879)(104.026,24.669)
\qbezier(104.026,24.669)(104.054,24.890)(104.082,25.112)
\qbezier(104.082,25.112)(104.173,24.918)(104.264,24.723)
\qbezier(104.264,24.723)(104.306,24.902)(104.348,25.081)
\qbezier(104.348,25.081)(104.432,24.912)(104.516,24.742)
\qbezier(104.516,24.742)(104.607,24.876)(104.698,25.009)
\qbezier(104.698,25.009)(104.712,24.870)(104.726,24.731)
\qbezier(104.726,24.731)(104.887,24.979)(105.048,25.227)
\qbezier(105.048,25.227)(105.076,25.017)(105.104,24.807)
\qbezier(105.104,24.807)(105.174,24.782)(105.244,24.758)
\qbezier(105.244,24.758)(105.251,25.028)(105.258,25.298)
\qbezier(105.258,25.298)(105.363,25.204)(105.468,25.110)
\qbezier(105.468,25.110)(105.517,24.903)(105.566,24.697)
\qbezier(105.566,24.697)(105.650,24.726)(105.734,24.755)
\qbezier(105.734,24.755)(105.818,24.898)(105.902,25.041)
\qbezier(105.902,25.041)(105.951,24.918)(106.000,24.794)
\qbezier(106.000,24.794)(106.126,24.965)(106.252,25.136)
\qbezier(106.252,25.136)(106.315,25.138)(106.378,25.139)
\qbezier(106.378,25.139)(106.399,24.974)(106.420,24.809)
\qbezier(106.420,24.809)(106.525,24.940)(106.630,25.071)
\qbezier(106.630,25.071)(106.693,24.909)(106.756,24.748)
\qbezier(106.756,24.748)(106.910,24.740)(107.064,24.732)
\qbezier(107.064,24.732)(107.071,24.954)(107.078,25.177)
\qbezier(107.078,25.177)(107.176,24.912)(107.274,24.648)
\qbezier(107.274,24.648)(107.288,24.838)(107.302,25.028)
\qbezier(107.302,25.028)(107.372,25.075)(107.442,25.122)
\qbezier(107.442,25.122)(107.449,24.900)(107.456,24.678)
\qbezier(107.456,24.678)(107.659,24.897)(107.862,25.116)
\qbezier(107.862,25.116)(107.883,24.921)(107.904,24.726)
\qbezier(107.904,24.726)(107.981,24.927)(108.058,25.128)
\qbezier(108.058,25.128)(108.086,24.972)(108.114,24.816)
\qbezier(108.114,24.816)(108.303,25.091)(108.492,25.365)
\qbezier(108.492,25.365)(108.499,25.032)(108.506,24.698)
\qbezier(108.506,24.698)(108.534,24.920)(108.562,25.142)
\qbezier(108.562,25.142)(108.583,24.890)(108.604,24.639)
\qbezier(108.604,24.639)(108.716,24.847)(108.828,25.056)
\qbezier(108.828,25.056)(108.919,24.712)(109.010,24.369)
\qbezier(109.010,24.369)(109.045,24.565)(109.080,24.760)
\qbezier(109.080,24.760)(109.171,25.233)(109.262,25.706)
\qbezier(109.262,25.706)(109.311,25.637)(109.360,25.568)
\qbezier(109.360,25.568)(109.388,25.153)(109.416,24.738)
\qbezier(109.416,24.738)(109.654,25.018)(109.892,25.298)
\qbezier(109.892,25.298)(109.899,24.967)(109.906,24.636)
\qbezier(109.906,24.636)(109.976,24.432)(110.046,24.229)
\qbezier(110.046,24.229)(110.102,24.709)(110.158,25.190)
\qbezier(110.158,25.190)(110.228,25.134)(110.298,25.079)
\qbezier(110.298,25.079)(110.354,24.804)(110.410,24.528)
\qbezier(110.410,24.528)(110.452,25.055)(110.494,25.583)
\qbezier(110.494,25.583)(110.550,24.971)(110.606,24.360)
\qbezier(110.606,24.360)(110.683,24.443)(110.760,24.526)
\qbezier(110.760,24.526)(110.844,24.803)(110.928,25.081)
\qbezier(110.928,25.081)(111.019,25.231)(111.110,25.381)
\qbezier(111.110,25.381)(111.138,24.689)(111.166,23.996)
\qbezier(111.166,23.996)(111.327,24.547)(111.488,25.097)
\qbezier(111.488,25.097)(111.537,24.811)(111.586,24.526)
\qbezier(111.586,24.526)(111.614,24.857)(111.642,25.189)
\qbezier(111.642,25.189)(111.712,24.818)(111.782,24.447)
\qbezier(111.782,24.447)(111.887,24.741)(111.992,25.035)
\qbezier(111.992,25.035)(112.006,24.824)(112.020,24.613)
\qbezier(112.020,24.613)(112.188,24.595)(112.356,24.578)
\qbezier(112.356,24.578)(112.363,24.936)(112.370,25.294)
\qbezier(112.370,25.294)(112.405,25.218)(112.440,25.142)
\qbezier(112.440,25.142)(112.468,24.737)(112.496,24.332)
\qbezier(112.496,24.332)(112.664,24.756)(112.832,25.180)
\qbezier(112.832,25.180)(112.874,24.862)(112.916,24.545)
\qbezier(112.916,24.545)(112.993,24.545)(113.070,24.545)
\qbezier(113.070,24.545)(113.105,24.966)(113.140,25.386)
\qbezier(113.140,25.386)(113.245,24.959)(113.350,24.532)
\qbezier(113.350,24.532)(113.434,24.864)(113.518,25.196)
\qbezier(113.518,25.196)(113.658,25.206)(113.798,25.216)
\qbezier(113.798,25.216)(113.812,24.640)(113.826,24.064)
\qbezier(113.826,24.064)(113.847,24.580)(113.868,25.095)
\qbezier(113.868,25.095)(113.882,24.590)(113.896,24.085)
\qbezier(113.896,24.085)(114.064,24.516)(114.232,24.947)
\qbezier(114.232,24.947)(114.288,24.691)(114.344,24.434)
\qbezier(114.344,24.434)(114.442,24.599)(114.540,24.763)
\qbezier(114.540,24.763)(114.582,24.603)(114.624,24.442)
\qbezier(114.624,24.442)(114.687,24.616)(114.750,24.789)
\qbezier(114.750,24.789)(114.813,24.606)(114.876,24.424)
\qbezier(114.876,24.424)(114.967,24.616)(115.058,24.808)
\qbezier(115.058,24.808)(115.072,24.635)(115.086,24.463)
\qbezier(115.086,24.463)(115.240,24.440)(115.394,24.417)
\qbezier(115.394,24.417)(115.443,24.612)(115.492,24.806)
\qbezier(115.492,24.806)(115.534,24.677)(115.576,24.549)
\qbezier(115.576,24.549)(115.639,24.674)(115.702,24.799)
\qbezier(115.702,24.799)(115.828,24.628)(115.954,24.456)
\qbezier(115.954,24.456)(115.961,24.667)(115.968,24.877)
\qbezier(115.968,24.877)(116.073,24.677)(116.178,24.478)
\qbezier(116.178,24.478)(116.220,24.648)(116.262,24.818)
\qbezier(116.262,24.818)(116.360,24.782)(116.458,24.746)
\qbezier(116.458,24.746)(116.472,24.606)(116.486,24.467)
\qbezier(116.486,24.467)(116.563,24.477)(116.640,24.488)
\qbezier(116.640,24.488)(116.696,24.644)(116.752,24.799)
\qbezier(116.752,24.799)(116.850,24.836)(116.948,24.873)
\qbezier(116.948,24.873)(117.067,24.629)(117.186,24.386)
\qbezier(117.186,24.386)(117.256,24.399)(117.326,24.412)
\qbezier(117.326,24.412)(117.382,24.585)(117.438,24.758)
\qbezier(117.438,24.758)(117.536,24.570)(117.634,24.382)
\qbezier(117.634,24.382)(117.683,24.594)(117.732,24.807)
\qbezier(117.732,24.807)(117.746,24.602)(117.760,24.397)
\qbezier(117.760,24.397)(117.879,24.637)(117.998,24.877)
\qbezier(117.998,24.877)(118.103,24.870)(118.208,24.863)
\qbezier(118.208,24.863)(118.257,24.661)(118.306,24.459)
\qbezier(118.306,24.459)(118.341,24.442)(118.376,24.425)
\qbezier(118.376,24.425)(118.418,24.604)(118.460,24.783)
\qbezier(118.460,24.783)(118.551,24.808)(118.642,24.832)
\qbezier(118.642,24.832)(118.670,24.617)(118.698,24.402)
\qbezier(118.698,24.402)(118.873,24.401)(119.048,24.400)
\qbezier(119.048,24.400)(119.055,24.638)(119.062,24.876)
\qbezier(119.062,24.876)(119.139,24.822)(119.216,24.767)
\qbezier(119.216,24.767)(119.237,24.547)(119.258,24.326)
\qbezier(119.258,24.326)(119.370,24.633)(119.482,24.939)
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

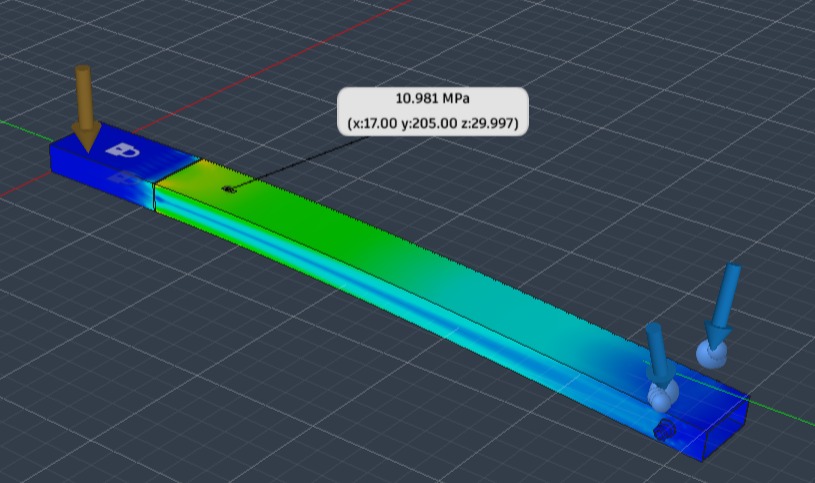
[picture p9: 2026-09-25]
fem/mesh_study/25mm.jpeg

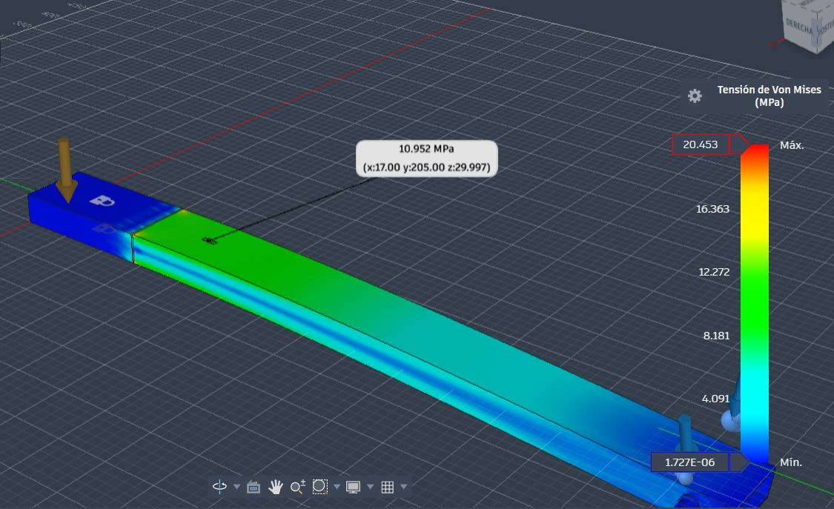
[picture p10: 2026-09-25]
fem/mesh_study/20mm.jpeg

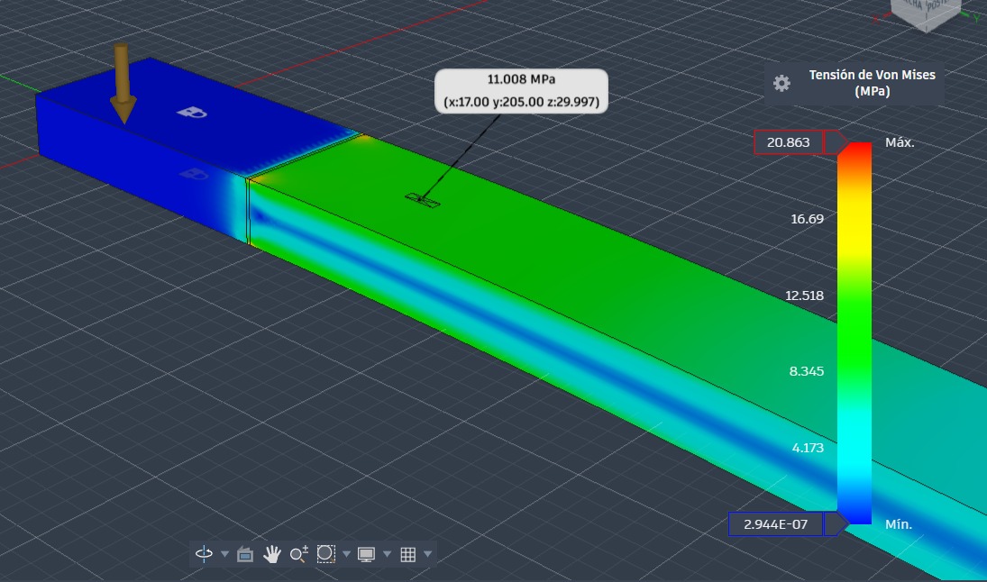
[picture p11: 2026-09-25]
fem/mesh_study/5mm.jpeg

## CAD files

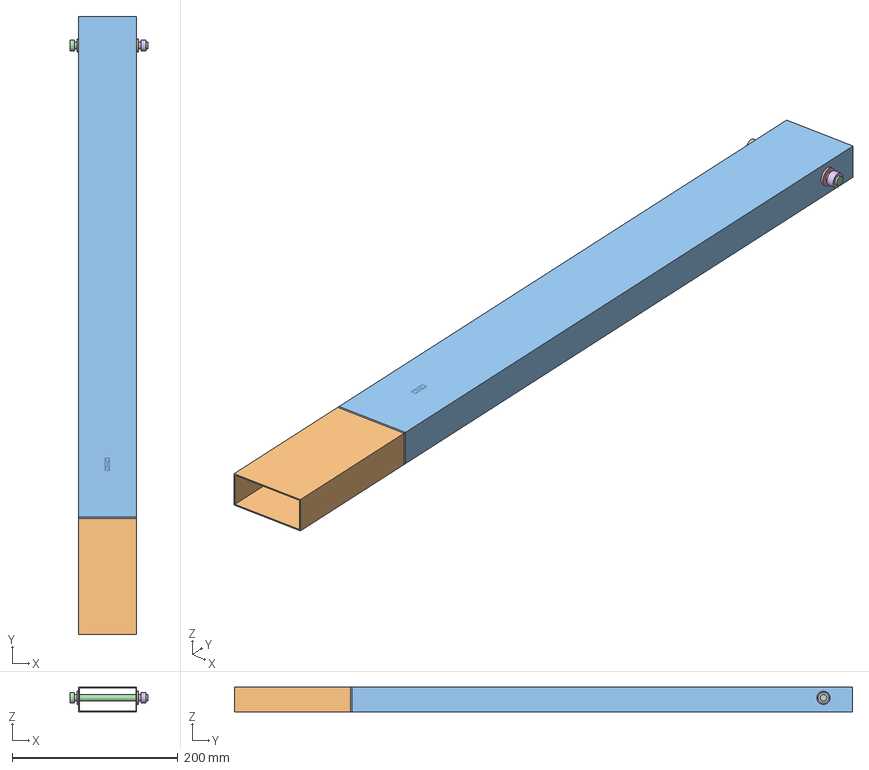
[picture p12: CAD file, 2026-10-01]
cad/step/VIGA_FEM.step
93.8 x 746.0 x 30.0 mm
Viga y galga - geometria original intacta
Tornillo
Arandela_lado_cuerda
Arandela_opuesta
Tuerca_cierre_idealizada

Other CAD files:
cad/native/VIGA_FEMa.f3d

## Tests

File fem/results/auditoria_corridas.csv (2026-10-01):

archivo | tamano_nominal | nodos | elementos | orden | E | gravedad_activa | total_fuerzas_Z_N | VM_max_global | VM_punto_galga_MPa | sigma_yy_galga_MPa | epsilon_yy_galga
fem/mesh_study/10mm.html | 10.00 mm | 80346 | 40572 | Parabólico | 68947.20 MPa | True | -46.764 | 21.018 MPa | 10.984
fem/mesh_study/15 mm.html | 15.00 mm | 48735 | 24301 | Parabólico | 68947.20 MPa | True | -46.764 | 20.722 MPa | 10.926
fem/mesh_study/20 mm.html | 20.00 mm | 46004 | 22549 | Parabólico | 68947.20 MPa | True | -46.764 | 20.453 MPa
fem/mesh_study/25 mm.html | 25.00 mm | 28614 | 13899 | Parabólico | 68947.20 MPa | True | -46.764 | 17.535 MPa
fem/mesh_study/5 mm.html | 5.00 mm | 86283 | 42748 | Parabólico | 68947.20 MPa | True | -46.764 | 20.863 MPa
fem/mesh_study/historico_2026-09-25/10mm.html | 10.00 mm | 80346 | 40572 | Parabólico | 68947.20 MPa | True | -46.764 | 21.018 MPa
fem/mesh_study/historico_2026-09-25/15 mm.html | 15.00 mm | 80346 | 40572 | Parabólico | 68947.20 MPa | True | -46.764 | 21.018 MPa
fem/results/Estudios_Informe_2026-09-23.html | - | 82873 | 41587 | Parabólico | 68947.20 MPa | True | -49.05
fem/results/Estudios_Informe_2026-09-24.html | - | 82873 | 41587 | Parabólico | 68947.20 MPa | True | -52.822 | 23.146 MPa

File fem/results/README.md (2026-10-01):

# Corridas históricas: configuraciones distintas

Los HTML históricos se conservan sin cambios. Las exportaciones anteriores de 10 y 15 mm están en `../mesh_study/historico_2026-09-25/`; los HTML vigentes de esas mallas están en `../mesh_study/`. La auditoría de `python/auditar_fem.py` produce `auditoria_corridas.csv` y `.json`, con huellas de los originales y campos longitudinales de galga vacíos porque no están exportados.

La actualización del 30 de septiembre incorpora dos HTML vigentes y capturas en `../mesh_study/`: se auditan nueve informes en total, incluidos los dos HTML anteriores archivados. Su comparación se documenta en `../mesh_study/actualizacion_2026-09-30/README.md`. La columna `VM_punto_galga_MPa` incorpora las lecturas de las capturas con su procedencia; `sigma_yy_galga_MPa` y `epsilon_yy_galga` permanecen vacías, porque Von Mises no es esa componente ni una deformación. El nuevo informe de 15 mm resuelve la repetición de recuentos anterior.

| Archivo o conjunto | Fuerzas aplicadas | Total vertical de fuerzas | Gravedad |
|---|---|---:|---|
| Informe 2026-09-23 | Una fuerza vertical de 49,05 N | −49,05 N | 9,807 m/s² |
| Informe 2026-09-24 | Dos fuerzas de 28,106 N | −52,822 N | 9,807 m/s² |
| Cinco mallas originales; dos HTML en `historico_2026-09-25/` | Dos fuerzas de 24,883 N, y = 707 mm | −46,764 N | 9,807 m/s² |

La nota del ZIP que atribuye 24,883 N a todas las corridas era incorrecta. Las componentes exportadas tienen redondeo: la recomposición trigonométrica de las mallas da 46,76474 N. El total de cada fila no incluye peso propio.

Los máximos globales de Von Mises no son lecturas de galga. El resumen de reacciones contiene extremos, no la suma de reacciones de apoyo; no permite verificar por sí solo el equilibrio global.

No se han recalculado estos estudios ni certificado sus contactos. Véase `../mesh_study/README.md` para completar la validación.

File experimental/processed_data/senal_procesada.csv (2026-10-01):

tiempo_s | epsilon_microstrain | epsilon_menos_base_microstrain
0.0 | 0.5370385524543609 | -2.9233827678798057
0.01 | 0.38228167372324195 | -3.0781396466109245
0.02 | 1.12167609945127 | -2.3387452208828963
0.03 | 0.15301231531849202 | -3.3074090050156744
0.04 | -0.569185449022714 | -4.029606769356881
0.05 | 0.9611872902660349 | -2.4992340300681315
0.06 | 0.38228167372324195 | -3.0781396466109245
0.07 | 0.840820718534944 | -2.6196006017992226
0.08 | 0.634478094249282 | -2.8259432260848847
0.09 | -1.16528437374897 | -4.625705694083137
0.1 | 1.30509194697782 | -2.155329373356347
0.11 | -0.305526073489198 | -3.7659473938233647
0.12 | -0.35711161486242105 | -3.8175329351965877
0.13 | 0.7720398339329999 | -2.6883814864011666
0.14 | 0.18167097913987598 | -3.2787503411942907
0.15 | -0.49467303146423897 | -3.9550943517984054
0.16 | 1.10448086733319 | -2.3559404530009767
0.17 | 1.1102126113042101 | -2.3502087090299564
0.18 | -1.04491830427031 | -4.505339624604477
0.19 | -1.12516235393777 | -4.585583674271937
0.2 | 3.15071780734671 | -0.30970351298745635
0.21 | 0.577160714331174 | -2.8832606060029926
0.22 | 0.9955777448671059 | -2.464843575467061
0.23 | 1.70631435739442 | -1.7541069629397466
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

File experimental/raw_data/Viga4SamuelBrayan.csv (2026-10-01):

Time | cDAQ1Mod2/ai0
17/09/2026 17:36:33.099000 | 5.37038552454361e-07
17/09/2026 17:36:33.109000 | 3.82281673723242e-07
17/09/2026 17:36:33.119000 | 1.12167609945127e-06
17/09/2026 17:36:33.129000 | 1.53012315318492e-07
17/09/2026 17:36:33.139000 | -5.69185449022714e-07
17/09/2026 17:36:33.149000 | 9.61187290266035e-07
17/09/2026 17:36:33.159000 | 3.82281673723242e-07
17/09/2026 17:36:33.169000 | 8.40820718534944e-07
17/09/2026 17:36:33.179000 | 6.34478094249282e-07
17/09/2026 17:36:33.189000 | -1.16528437374897e-06
17/09/2026 17:36:33.199000 | 1.30509194697782e-06
17/09/2026 17:36:33.209000 | -3.05526073489198e-07
17/09/2026 17:36:33.219000 | -3.57111614862421e-07
17/09/2026 17:36:33.229000 | 7.72039833933e-07
17/09/2026 17:36:33.239000 | 1.81670979139876e-07
17/09/2026 17:36:33.249000 | -4.94673031464239e-07
17/09/2026 17:36:33.259000 | 1.10448086733319e-06
17/09/2026 17:36:33.269000 | 1.11021261130421e-06
17/09/2026 17:36:33.279000 | -1.04491830427031e-06
17/09/2026 17:36:33.289000 | -1.12516235393777e-06
17/09/2026 17:36:33.299000 | 3.15071780734671e-06
17/09/2026 17:36:33.309000 | 5.77160714331174e-07
17/09/2026 17:36:33.319000 | 9.95577744867106e-07
17/09/2026 17:36:33.329000 | 1.70631435739442e-06
17/09/2026 17:36:33.339000 | 5.48502026934638e-07
17/09/2026 17:36:33.349000 | 1.08155389213243e-06
17/09/2026 17:36:33.359000 | -2.31013615067225e-07
17/09/2026 17:36:33.369000 | 1.33375067947472e-06
17/09/2026 17:36:33.379000 | -2.42477070960728e-07
17/09/2026 17:36:33.389000 | 2.56183513070576e-07
17/09/2026 17:36:33.399000 | 5.48502026934638e-07
17/09/2026 17:36:33.409000 | 4.41094083773193e-08
17/09/2026 17:36:33.419000 | 1.67765560268895e-06
17/09/2026 17:36:33.429000 | 1.0987491234305e-06
17/09/2026 17:36:33.439000 | -3.61348230574593e-08
17/09/2026 17:36:33.449000 | 3.24964323872004e-07
17/09/2026 17:36:33.459000 | 6.68868525480171e-07
17/09/2026 17:36:33.469000 | 6.51673309557224e-07
17/09/2026 17:36:33.479000 | -3.57111614862421e-07
17/09/2026 17:36:33.489000 | -5.0613648107105e-07
17/09/2026 17:36:33.499000 | 2.05021954711146e-06
17/09/2026 17:36:33.509000 | 3.98729098578116e-09
17/09/2026 17:36:33.519000 | 1.21911575973714e-06
17/09/2026 17:36:33.529000 | -1.33723584930051e-06
17/09/2026 17:36:33.539000 | 4.41094083773193e-08
17/09/2026 17:36:33.549000 | 1.81670979139876e-07
17/09/2026 17:36:33.559000 | 8.42315291172089e-08
17/09/2026 17:36:33.569000 | 1.58021584946885e-06
17/09/2026 17:36:33.579000 | 4.05208615577082e-07
17/09/2026 17:36:33.589000 | -3.68575067749245e-07
17/09/2026 17:36:33.599000 | 5.19843341246448e-07
17/09/2026 17:36:33.609000 | 4.68257711312681e-07
17/09/2026 17:36:33.619000 | 6.34478094249282e-07
17/09/2026 17:36:33.629000 | -3.39916435019683e-07
17/09/2026 17:36:33.639000 | 7.89235054160979e-07
17/09/2026 17:36:33.649000 | 3.82281673723242e-07
17/09/2026 17:36:33.659000 | 8.58015941222942e-07
17/09/2026 17:36:33.669000 | -1.74443979681807e-09
17/09/2026 17:36:33.679000 | 5.48502026934638e-07
17/09/2026 17:36:33.689000 | 7.37649395322002e-07
17/09/2026 17:36:33.699000 | 2.50451779281293e-07
17/09/2026 17:36:33.709000 | 5.42770289660333e-07
17/09/2026 17:36:33.719000 | 4.10940351211377e-07
17/09/2026 17:36:33.729000 | 5.02648130653539e-07
17/09/2026 17:36:33.739000 | 1.2435365320545e-07
17/09/2026 17:36:33.749000 | 2.21793111359831e-07
17/09/2026 17:36:33.759000 | 1.42545863494493e-06
17/09/2026 17:36:33.769000 | 1.40253164443736e-06
17/09/2026 17:36:33.779000 | -1.27418698207242e-06
17/09/2026 17:36:33.789000 | -1.01052799316999e-06
17/09/2026 17:36:33.799000 | -5.69185449022714e-07
17/09/2026 17:36:33.809000 | -3.61348230574593e-08
17/09/2026 17:36:33.819000 | 8.98138129886623e-07
17/09/2026 17:36:33.829000 | -6.78088192373157e-07
17/09/2026 17:36:33.839000 | -4.18665533617227e-08
17/09/2026 17:36:33.849000 | -1.09077204857746e-06
17/09/2026 17:36:33.859000 | 3.02037385844855e-07
17/09/2026 17:36:33.869000 | 2.67646980854143e-07
17/09/2026 17:36:33.879000 | 1.54507527559807e-08
17/09/2026 17:36:33.889000 | 1.75939246238932e-07
17/09/2026 17:36:33.899000 | -9.9906455558988e-07
17/09/2026 17:36:33.909000 | 8.29357237084614e-07
17/09/2026 17:36:33.919000 | 1.43692213060872e-06
17/09/2026 17:36:33.929000 | -9.18820484875765e-07
17/09/2026 17:36:33.939000 | 9.8984600226276e-07
17/09/2026 17:36:33.949000 | 1.26496972435212e-06
17/09/2026 17:36:33.959000 | 4.41094083773193e-08
17/09/2026 17:36:33.969000 | 1.40826339196175e-06
17/09/2026 17:36:33.979000 | -1.85159788759863e-07
17/09/2026 17:36:33.989000 | 5.94355927589101e-07
17/09/2026 17:36:33.999000 | -2.46713622439314e-08
17/09/2026 17:36:34.009000 | 7.54844614319972e-07
17/09/2026 17:36:34.019000 | 1.31655543977158e-06
17/09/2026 17:36:34.029000 | -8.44308121505843e-07
17/09/2026 17:36:34.039000 | 1.00130948753979e-06
17/09/2026 17:36:34.049000 | -7.06746804944312e-07
17/09/2026 17:36:34.059000 | 4.16672086914005e-07
17/09/2026 17:36:34.069000 | -1.73696331499686e-07
17/09/2026 17:36:34.079000 | 1.45411737461691e-06
17/09/2026 17:36:34.089000 | 5.77160714331174e-07
17/09/2026 17:36:34.099000 | 9.95577744867106e-07
17/09/2026 17:36:34.109000 | 7.14722437614717e-07
17/09/2026 17:36:34.119000 | 1.04716343138131e-06
17/09/2026 17:36:34.129000 | 1.1289018883857e-07
17/09/2026 17:36:34.139000 | -1.07930861291069e-06
17/09/2026 17:36:34.149000 | 8.86674647069617e-07
17/09/2026 17:36:34.159000 | 8.92406388443953e-07
17/09/2026 17:36:34.169000 | -5.33300137652484e-08
17/09/2026 17:36:34.179000 | -1.89894357418183e-06
17/09/2026 17:36:34.189000 | -5.97844068085558e-07
17/09/2026 17:36:34.199000 | 3.04181422137018e-06
17/09/2026 17:36:34.209000 | 2.04597911426991e-07
17/09/2026 17:36:34.219000 | 8.75211164525945e-07
17/09/2026 17:36:34.229000 | 1.17326179949553e-06
17/09/2026 17:36:34.239000 | 4.85452920675582e-07
17/09/2026 17:36:34.249000 | 4.39599030407857e-07
17/09/2026 17:36:34.259000 | 4.68257711312681e-07
17/09/2026 17:36:34.269000 | 3.65086468050366e-07
17/09/2026 17:36:34.279000 | -6.3796613190353e-07
17/09/2026 17:36:34.289000 | 2.44720045560344e-07
17/09/2026 17:36:34.299000 | -3.8577024656698e-07
17/09/2026 17:36:34.309000 | 5.48502026934638e-07
17/09/2026 17:36:34.319000 | 6.86063742018122e-07
17/09/2026 17:36:34.329000 | 4.45330766452154e-07
17/09/2026 17:36:34.339000 | -1.62232873966175e-07
17/09/2026 17:36:34.349000 | 1.64899684969184e-06
17/09/2026 17:36:34.359000 | 6.28746355949969e-07
17/09/2026 17:36:34.369000 | 1.9298527027277e-06
17/09/2026 17:36:34.379000 | 3.36427793295582e-07
17/09/2026 17:36:34.389000 | -3.05526073489198e-07
17/09/2026 17:36:34.399000 | 9.32528579977658e-07
17/09/2026 17:36:34.409000 | 7.0899069835873e-07
17/09/2026 17:36:34.419000 | 1.31655543977158e-06
17/09/2026 17:36:34.429000 | -1.22110770446374e-07
17/09/2026 17:36:34.439000 | 8.92406388443953e-07
17/09/2026 17:36:34.449000 | -7.62569337522957e-08
17/09/2026 17:36:34.459000 | 1.20192052413403e-06
17/09/2026 17:36:34.469000 | 5.14111604313811e-07
17/09/2026 17:36:34.479000 | -9.24552204656655e-07
17/09/2026 17:36:34.489000 | -2.46713622439314e-08
17/09/2026 17:36:34.499000 | 6.57405048129873e-07
17/09/2026 17:36:34.509000 | -4.31624053740925e-07
17/09/2026 17:36:34.519000 | 1.35094591979287e-06
17/09/2026 17:36:34.529000 | -9.41747363589325e-07
17/09/2026 17:36:34.539000 | 9.09601612976966e-07
17/09/2026 17:36:34.549000 | 3.07620482480298e-06
17/09/2026 17:36:34.559000 | 6.91795481000773e-07
17/09/2026 17:36:34.569000 | 6.7460026425782e-07
17/09/2026 17:36:34.579000 | 9.56949928007521e-08
17/09/2026 17:36:34.589000 | 4.62525974995049e-07
17/09/2026 17:36:34.599000 | 5.31306815316723e-07
17/09/2026 17:36:34.609000 | 1.05289517466899e-06
17/09/2026 17:36:34.619000 | 9.15333354624638e-07
17/09/2026 17:36:34.629000 | -2.99369858058901e-06
17/09/2026 17:36:34.639000 | 6.63136786770855e-07
17/09/2026 17:36:34.649000 | 9.8984600226276e-07
17/09/2026 17:36:34.659000 | 1.81670979139876e-07
17/09/2026 17:36:34.669000 | 6.2301461771899e-07
17/09/2026 17:36:34.679000 | -2.38040681602613e-06
17/09/2026 17:36:34.689000 | 3.76549938430616e-07
17/09/2026 17:36:34.699000 | 4.22403822684968e-07
17/09/2026 17:36:34.709000 | -9.91838526460041e-08
17/09/2026 17:36:34.719000 | 3.99476880011122e-07
17/09/2026 17:36:34.729000 | 1.01850471596789e-06
17/09/2026 17:36:34.739000 | 5.55728711041906e-08
17/09/2026 17:36:34.749000 | 2.09607359099399e-06
17/09/2026 17:36:34.759000 | 4.05208615577082e-07
17/09/2026 17:36:34.769000 | 8.63747682255609e-07
17/09/2026 17:36:34.779000 | 1.18621920987843e-07
17/09/2026 17:36:34.789000 | -1.5722360997616e-06
17/09/2026 17:36:34.799000 | 2.00436550760237e-06
17/09/2026 17:36:34.809000 | 2.44720045560344e-07
17/09/2026 17:36:34.819000 | 3.83776771163841e-08
17/09/2026 17:36:34.829000 | -4.2016060235744e-07
17/09/2026 17:36:34.839000 | 3.83776771163841e-08
17/09/2026 17:36:34.849000 | 9.72650774859723e-07
17/09/2026 17:36:34.859000 | 8.99632609248136e-08
17/09/2026 17:36:34.869000 | 7.66308093993674e-07
17/09/2026 17:36:34.879000 | 6.51673309557224e-07
17/09/2026 17:36:34.889000 | -6.8955163760662e-07
17/09/2026 17:36:34.899000 | 1.46558087096403e-06
17/09/2026 17:36:34.909000 | 8.42315291172089e-08
17/09/2026 17:36:34.919000 | 1.30509194697782e-06
17/09/2026 17:36:34.929000 | -1.8416264894647e-06
17/09/2026 17:36:34.939000 | -9.53210802536104e-07
17/09/2026 17:36:34.949000 | -9.07357045108984e-07
17/09/2026 17:36:34.959000 | 7.03258959171077e-07
17/09/2026 17:36:34.969000 | 1.51143485908591e-06
17/09/2026 17:36:34.979000 | 1.07009040494205e-06
17/09/2026 17:36:34.989000 | -5.86380620665421e-07
17/09/2026 17:36:34.999000 | -5.23331654968765e-07
17/09/2026 17:36:35.009000 | -1.50769416159328e-07
17/09/2026 17:36:35.019000 | 7.03258959171077e-07
17/09/2026 17:36:35.029000 | 4.5679423874575e-07
17/09/2026 17:36:35.039000 | -8.78698444496195e-07
17/09/2026 17:36:35.049000 | -1.11943063654855e-06
17/09/2026 17:36:35.059000 | 1.47280582759216e-07
17/09/2026 17:36:35.069000 | 5.54233764277278e-07
17/09/2026 17:36:35.079000 | -1.52638240137456e-06
17/09/2026 17:36:35.089000 | 5.31306815316723e-07
17/09/2026 17:36:35.099000 | -2.65403981927733e-07
17/09/2026 17:36:35.109000 | 6.11551141462033e-07
17/09/2026 17:36:35.119000 | 9.38260321898666e-07
17/09/2026 17:36:35.129000 | -1.01052799316999e-06
17/09/2026 17:36:35.139000 | 3.42159528109871e-07
17/09/2026 17:36:35.149000 | 2.34827091052194e-06
17/09/2026 17:36:35.159000 | 1.39106814959358e-06
17/09/2026 17:36:35.169000 | 7.77771573940658e-07
17/09/2026 17:36:35.179000 | 9.38260321898666e-07
17/09/2026 17:36:35.189000 | 4.28135558524264e-07
17/09/2026 17:36:35.199000 | 9.66919032528712e-07
17/09/2026 17:36:35.209000 | 6.05819403436055e-07
17/09/2026 17:36:35.219000 | 1.32228718627096e-06
17/09/2026 17:36:35.229000 | -7.69795746587503e-07
17/09/2026 17:36:35.239000 | 5.48502026934638e-07
17/09/2026 17:36:35.249000 | 2.50451779281293e-07
17/09/2026 17:36:35.259000 | 5.25575078247419e-07
17/09/2026 17:36:35.269000 | 1.49997136164544e-06
17/09/2026 17:36:35.279000 | -1.02199143047677e-06
17/09/2026 17:36:35.289000 | 7.3191765579268e-07
17/09/2026 17:36:35.299000 | 2.33680739312791e-06
17/09/2026 17:36:35.309000 | -7.64064024961608e-07
17/09/2026 17:36:35.319000 | 7.0899069835873e-07
17/09/2026 17:36:35.329000 | -1.14235750569543e-06
17/09/2026 17:36:35.339000 | -4.37355779330167e-07
17/09/2026 17:36:35.349000 | 1.54009360388299e-06
17/09/2026 17:36:35.359000 | 1.05289517466899e-06
17/09/2026 17:36:35.369000 | 8.86674647069617e-07
17/09/2026 17:36:35.379000 | -1.20540639021182e-06
17/09/2026 17:36:35.389000 | 5.94355927589101e-07
17/09/2026 17:36:35.399000 | 1.58744047946101e-07
17/09/2026 17:36:35.409000 | 2.50451779281293e-07
17/09/2026 17:36:35.419000 | 1.15033482101474e-06
17/09/2026 17:36:35.429000 | -1.48052869861419e-06
17/09/2026 17:36:35.439000 | -4.2589232808335e-07
17/09/2026 17:36:35.449000 | -1.79428060163941e-07
17/09/2026 17:36:35.459000 | 7.89235054160979e-07
17/09/2026 17:36:35.469000 | 1.41548850268274e-07
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

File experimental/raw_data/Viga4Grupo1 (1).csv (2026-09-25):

Time | cDAQ1Mod2/ai0
15/09/2026 21:06:06.684000 | -1.31117791448079e-07
15/09/2026 21:06:06.694000 | -7.32949522217293e-07
15/09/2026 21:06:06.704000 | 4.70713939321188e-07
15/09/2026 21:06:06.714000 | -3.25996637601939e-07
15/09/2026 21:06:06.724000 | -1.26026875298652e-06
15/09/2026 21:06:06.734000 | 5.80293239365507e-08
15/09/2026 21:06:06.744000 | 4.1626249701348e-07
15/09/2026 21:06:06.754000 | 6.91385573936554e-07
15/09/2026 21:06:06.764000 | 7.54434612398079e-07
15/09/2026 21:06:06.774000 | -1.69014856067885e-06
15/09/2026 21:06:06.784000 | 3.15957208551936e-07
15/09/2026 21:06:06.794000 | 2.29981247013492e-07
15/09/2026 21:06:06.804000 | -1.07112163760189e-06
15/09/2026 21:06:06.814000 | -7.41547118371164e-07
15/09/2026 21:06:06.824000 | -1.84490529144805e-06
15/09/2026 21:06:06.834000 | 1.04961874701348e-06
15/09/2026 21:06:06.844000 | -8.24657214524966e-07
15/09/2026 21:06:06.854000 | 3.07359612398065e-07
15/09/2026 21:06:06.864000 | -5.32338945294204e-07
15/09/2026 21:06:06.874000 | -5.75326926063452e-07
15/09/2026 21:06:06.884000 | 7.94556727782686e-07
15/09/2026 21:06:06.894000 | 4.93640862398106e-07
15/09/2026 21:06:06.904000 | 1.52535240085965e-06
15/09/2026 21:06:06.914000 | -1.15136586837116e-06
15/09/2026 21:06:06.924000 | -8.52639452942424e-08
15/09/2026 21:06:06.934000 | 2.41444708551951e-07
15/09/2026 21:06:06.944000 | -3.14533176063426e-07
15/09/2026 21:06:06.954000 | -1.05325002986519e-07
15/09/2026 21:06:06.964000 | 1.10980192009037e-06
15/09/2026 21:06:06.974000 | -2.50118846452497e-06
15/09/2026 21:06:06.984000 | 5.50958170090402e-07
15/09/2026 21:06:06.994000 | -1.67868509914039e-06
15/09/2026 21:06:07.004000 | -4.17704329909612e-07
15/09/2026 21:06:07.014000 | -6.3551009914039e-07
15/09/2026 21:06:07.024000 | -1.94807644529423e-06
15/09/2026 21:06:07.034000 | 8.43276439321165e-07
15/09/2026 21:06:07.044000 | 7.60166343167309e-07
15/09/2026 21:06:07.054000 | 4.24860093167298e-07
15/09/2026 21:06:07.064000 | -1.48312983755768e-07
15/09/2026 21:06:07.074000 | -1.19435384914035e-06
15/09/2026 21:06:07.084000 | 1.23589999701347e-06
15/09/2026 21:06:07.094000 | 2.50042304705769e-07
15/09/2026 21:06:07.104000 | -3.63252887601904e-07
15/09/2026 21:06:07.114000 | 1.75529804705784e-07
15/09/2026 21:06:07.124000 | -2.08496156832705e-07
15/09/2026 21:06:07.134000 | 9.3211826624425e-07
15/09/2026 21:06:07.144000 | 6.94927854750099e-08
15/09/2026 21:06:07.154000 | -5.43802406832663e-07
15/09/2026 21:06:07.164000 | 3.38884131628854e-07
15/09/2026 21:06:07.174000 | -4.32033656832659e-07
15/09/2026 21:06:07.184000 | 1.13272884316734e-06
15/09/2026 21:06:07.194000 | 1.12126538162888e-06
15/09/2026 21:06:07.204000 | 1.98456727782702e-07
15/09/2026 21:06:07.214000 | 9.81514393211578e-08
15/09/2026 21:06:07.224000 | -2.03978413760191e-06
15/09/2026 21:06:07.234000 | 7.54434612398079e-07
15/09/2026 21:06:07.244000 | 5.82482689321138e-07
15/09/2026 21:06:07.254000 | -1.942344714525e-06
15/09/2026 21:06:07.264000 | 1.16711922778272e-06
15/09/2026 21:06:07.274000 | -1.32904952221728e-06
15/09/2026 21:06:07.284000 | 5.9967788162888e-07
15/09/2026 21:06:07.294000 | -7.95998560678818e-07
15/09/2026 21:06:07.304000 | -1.24307356067883e-06
15/09/2026 21:06:07.314000 | -9.38615414480601e-08
15/09/2026 21:06:07.324000 | -2.26905336837114e-06
15/09/2026 21:06:07.334000 | 5.28031247013484e-07
15/09/2026 21:06:07.344000 | 1.39925432393654e-06
15/09/2026 21:06:07.354000 | -1.19435384914035e-06
15/09/2026 21:06:07.364000 | -9.93743272217319e-07
15/09/2026 21:06:07.374000 | -2.64161586837112e-06
15/09/2026 21:06:07.384000 | 7.11446631628831e-07
15/09/2026 21:06:07.394000 | -1.22520195294208e-07
15/09/2026 21:06:07.404000 | 1.1298629777827e-06
15/09/2026 21:06:07.414000 | -8.36120676063479e-07
15/09/2026 21:06:07.424000 | -2.04551586837114e-06
15/09/2026 21:06:07.434000 | 8.06020189321146e-07
15/09/2026 21:06:07.444000 | -3.05935579909608e-07
15/09/2026 21:06:07.454000 | -5.40936541448075e-07
15/09/2026 21:06:07.464000 | -5.26607214524974e-07
15/09/2026 21:06:07.474000 | -1.41215961837113e-06
15/09/2026 21:06:07.484000 | 3.84737977782691e-07
15/09/2026 21:06:07.494000 | 1.69443845855195e-06
15/09/2026 21:06:07.504000 | -1.68374041448045e-07
15/09/2026 21:06:07.514000 | -1.27173221452498e-06
15/09/2026 21:06:07.524000 | -2.36362692606346e-06
15/09/2026 21:06:07.534000 | 5.05104323936565e-07
15/09/2026 21:06:07.544000 | -5.09412022217285e-07
15/09/2026 21:06:07.554000 | -3.46057695294215e-07
15/09/2026 21:06:07.564000 | 4.96506727782694e-07
15/09/2026 21:06:07.574000 | -2.25472404144804e-06
15/09/2026 21:06:07.584000 | -4.80076952942234e-08
15/09/2026 21:06:07.594000 | 4.44921150859628e-07
15/09/2026 21:06:07.604000 | 8.09562470134691e-08
15/09/2026 21:06:07.614000 | 1.22157067009037e-06
15/09/2026 21:06:07.624000 | -1.20581731067881e-06
15/09/2026 21:06:07.634000 | 8.74800958551954e-07
15/09/2026 21:06:07.644000 | -8.04596156832689e-07
15/09/2026 21:06:07.654000 | 6.14007208551928e-07
15/09/2026 21:06:07.664000 | -1.1965432990962e-07
15/09/2026 21:06:07.674000 | -1.17715865683267e-06
15/09/2026 21:06:07.684000 | 8.95538431673401e-08
15/09/2026 21:06:07.694000 | -1.94166829909605e-07
15/09/2026 21:06:07.704000 | -1.91300964525016e-07
15/09/2026 21:06:07.714000 | 3.84737977782691e-07
15/09/2026 21:06:07.724000 | -2.24899231067881e-06
15/09/2026 21:06:07.734000 | 2.21383650859621e-07
15/09/2026 21:06:07.744000 | 8.69069227782724e-07
15/09/2026 21:06:07.754000 | 4.96506727782694e-07
15/09/2026 21:06:07.764000 | 7.52245162442395e-08
15/09/2026 21:06:07.774000 | -1.27746394529421e-06
15/09/2026 21:06:07.784000 | 1.21010720855191e-06
15/09/2026 21:06:07.794000 | -7.87400964525001e-07
15/09/2026 21:06:07.804000 | 1.98456727782702e-07
15/09/2026 21:06:07.814000 | 2.15651920090391e-07
15/09/2026 21:06:07.824000 | 1.46871150859636e-07
15/09/2026 21:06:07.834000 | 7.05714900859601e-07
15/09/2026 21:06:07.844000 | -4.89350964525009e-07
15/09/2026 21:06:07.854000 | -2.08496156832705e-07
15/09/2026 21:06:07.864000 | -5.98253849140371e-07
15/09/2026 21:06:07.874000 | -1.3663057722173e-06
15/09/2026 21:06:07.884000 | 6.65592785474994e-07
15/09/2026 21:06:07.894000 | 3.99067304705791e-07
15/09/2026 21:06:07.904000 | 3.64676920090414e-07
15/09/2026 21:06:07.914000 | 5.5382403547499e-07
15/09/2026 21:06:07.924000 | -2.65307932990963e-06
15/09/2026 21:06:07.934000 | 5.30897112398072e-07
15/09/2026 21:06:07.944000 | -5.08735606788115e-08
15/09/2026 21:06:07.954000 | 9.63642785474986e-07
15/09/2026 21:06:07.964000 | -6.49839426063437e-07
15/09/2026 21:06:07.974000 | -1.52392836837114e-06
15/09/2026 21:06:07.984000 | 9.75106247013445e-07
15/09/2026 21:06:07.994000 | -2.65813464525001e-07
15/09/2026 21:06:08.004000 | -1.97032695294246e-07
15/09/2026 21:06:08.014000 | 4.07664900859609e-07
15/09/2026 21:06:08.024000 | -1.89649086837117e-06
15/09/2026 21:06:08.034000 | 6.45531727782717e-07
15/09/2026 21:06:08.044000 | -1.88435099140375e-07
15/09/2026 21:06:08.054000 | -5.52400002986534e-07
15/09/2026 21:06:08.064000 | -2.15384914038667e-09
15/09/2026 21:06:08.074000 | -9.53621156832659e-07
15/09/2026 21:06:08.084000 | 1.01522836239811e-06
15/09/2026 21:06:08.094000 | 4.1626249701348e-07
15/09/2026 21:06:08.104000 | -3.43191829909627e-07
15/09/2026 21:06:08.114000 | 1.10980192009037e-06
15/09/2026 21:06:08.124000 | -1.78185625298652e-06
15/09/2026 21:06:08.134000 | 4.53518747013446e-07
15/09/2026 21:06:08.144000 | -8.16059618371148e-07
15/09/2026 21:06:08.154000 | -3.63252887601904e-07
15/09/2026 21:06:08.164000 | -1.02240192606347e-06
15/09/2026 21:06:08.174000 | -8.38986541448067e-07
15/09/2026 21:06:08.184000 | 3.47481727782725e-07
15/09/2026 21:06:08.194000 | 7.14312497013472e-07
15/09/2026 21:06:08.204000 | -1.08545096452499e-06
15/09/2026 21:06:08.214000 | -2.5721586837113e-07
15/09/2026 21:06:08.224000 | -2.44387115683267e-06
15/09/2026 21:06:08.234000 | 9.0632547778269e-07
15/09/2026 21:06:08.244000 | 7.22910093167343e-07
15/09/2026 21:06:08.254000 | 1.98456727782702e-07
15/09/2026 21:06:08.264000 | -8.01730291448048e-07
15/09/2026 21:06:08.274000 | -1.23161009914037e-06
15/09/2026 21:06:08.284000 | 1.54827932393656e-06
15/09/2026 21:06:08.294000 | -1.99898560678834e-07
15/09/2026 21:06:08.304000 | 2.15651920090391e-07
15/09/2026 21:06:08.314000 | 6.28336535475028e-07
15/09/2026 21:06:08.324000 | -3.17399041448067e-07
15/09/2026 21:06:08.334000 | 1.11553365085965e-06
15/09/2026 21:06:08.344000 | -1.55258702221728e-06
15/09/2026 21:06:08.354000 | 3.79682662442204e-08
15/09/2026 21:06:08.364000 | -3.20264906832709e-07
15/09/2026 21:06:08.374000 | 2.04188458551932e-07
15/09/2026 21:06:08.384000 | 3.41749997013495e-07
15/09/2026 21:06:08.394000 | -7.81669233755771e-07
15/09/2026 21:06:08.404000 | -9.04901445294234e-07
15/09/2026 21:06:08.414000 | -6.89961541448044e-07
15/09/2026 21:06:08.424000 | -2.22606538760189e-06
15/09/2026 21:06:08.434000 | 1.37919326624426e-06
15/09/2026 21:06:08.444000 | -2.19959618371164e-07
15/09/2026 21:06:08.454000 | 1.02955768932115e-06
15/09/2026 21:06:08.464000 | 3.13091343167294e-07
15/09/2026 21:06:08.474000 | -3.94100991403523e-08
15/09/2026 21:06:08.484000 | 1.06394807393653e-06
15/09/2026 21:06:08.494000 | -6.039855799096e-07
15/09/2026 21:06:08.504000 | 8.00288458551916e-07
15/09/2026 21:06:08.514000 | 2.72969227782687e-07
15/09/2026 21:06:08.524000 | -1.53252596452501e-06
15/09/2026 21:06:08.534000 | 3.79682662442204e-08
15/09/2026 21:06:08.544000 | 7.14312497013472e-07
15/09/2026 21:06:08.554000 | -5.35204810678845e-07
15/09/2026 21:06:08.564000 | -4.29167791448071e-07
15/09/2026 21:06:08.574000 | -5.15143752986515e-07
15/09/2026 21:06:08.584000 | 4.2199422778271e-07
15/09/2026 21:06:08.594000 | -6.06851445294242e-07
15/09/2026 21:06:08.604000 | 7.40105285475032e-07
15/09/2026 21:06:08.614000 | -7.55876445294211e-07
15/09/2026 21:06:08.624000 | -2.0139913491404e-06
15/09/2026 21:06:08.634000 | -8.59047599140397e-07
15/09/2026 21:06:08.644000 | -2.60081733755772e-07
15/09/2026 21:06:08.654000 | -1.68374041448045e-07
15/09/2026 21:06:08.664000 | -6.78498079909585e-07
15/09/2026 21:06:08.674000 | -1.80764904144808e-06
15/09/2026 21:06:08.684000 | 8.60471631628853e-07
15/09/2026 21:06:08.694000 | -2.34288945294212e-07
15/09/2026 21:06:08.704000 | 6.94927854750099e-08
15/09/2026 21:06:08.714000 | -5.08735606788115e-08
15/09/2026 21:06:08.724000 | -3.08125029865346e-08
15/09/2026 21:06:08.734000 | 2.5112100931673e-06
15/09/2026 21:06:08.744000 | -7.58742310678853e-07
15/09/2026 21:06:08.754000 | 9.0059374701346e-07
15/09/2026 21:06:08.764000 | 9.46447593167297e-07
15/09/2026 21:06:08.774000 | -9.10633176063463e-07
15/09/2026 21:06:08.784000 | 1.34480288162883e-06
15/09/2026 21:06:08.794000 | 6.11141343167339e-07
15/09/2026 21:06:08.804000 | 3.73274516244231e-07
15/09/2026 21:06:08.814000 | 1.64066343167325e-07
15/09/2026 21:06:08.824000 | -2.41234663760194e-06
15/09/2026 21:06:08.834000 | 6.99983170090371e-07
15/09/2026 21:06:08.844000 | 6.66269200903684e-08
15/09/2026 21:06:08.854000 | 2.12786054705803e-07
15/09/2026 21:06:08.864000 | -7.88557990961626e-09
15/09/2026 21:06:08.874000 | -6.98559137601915e-07
15/09/2026 21:06:08.884000 | 1.64285288162888e-06
15/09/2026 21:06:08.894000 | -6.06851445294242e-07
15/09/2026 21:06:08.904000 | 3.18823073936524e-07
15/09/2026 21:06:08.914000 | 6.14007208551928e-07
15/09/2026 21:06:08.924000 | -1.40069615683267e-06
15/09/2026 21:06:08.934000 | 1.37346153547503e-06
15/09/2026 21:06:08.944000 | -5.66052914480945e-08
15/09/2026 21:06:08.954000 | -6.89961541448044e-07
15/09/2026 21:06:08.964000 | -4.43497118371118e-07
15/09/2026 21:06:08.974000 | -1.90508846452498e-06
15/09/2026 21:06:08.984000 | 7.80227400859639e-07
15/09/2026 21:06:08.994000 | 5.50958170090402e-07
15/09/2026 21:06:09.004000 | -2.80142791448048e-07
15/09/2026 21:06:09.014000 | -5.66729329909581e-07
15/09/2026 21:06:09.024000 | -1.68441682990962e-06
15/09/2026 21:06:09.034000 | 1.37919326624426e-06
15/09/2026 21:06:09.044000 | -2.8874038760192e-07
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

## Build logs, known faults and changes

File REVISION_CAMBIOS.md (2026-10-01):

# Revisión de GalgaLab

Comparación realizada el 30 de septiembre de 2026 entre `cambios_repo.zip` y `main` de [brayansan00/galgalab](https://github.com/brayansan00/galgalab), commit `dfa231fbb436338dee7460102a4b27766cca2854`.

## Actualización: nuevas exportaciones y lectura local

El usuario aportó nuevos informes de 10 y 15 mm y confirmó que las dos capturas corresponden a Von Mises, en ese orden. La malla nueva de 15 mm tiene **48 735 nodos y 24 301 elementos**, frente a **80 346 y 40 572** de la de 10 mm. Sus máximos globales son 20,722 y 21,018 MPa. La repetición detectada queda limitada al archivo anterior de 15 mm; los nuevos informes sí distinguen las resoluciones.

En el mismo punto (17; 205; 29,997) mm, las capturas dan **10,926 MPa para 15 mm y 10,984 MPa para 10 mm**. La diferencia es 0,058 MPa y la variación respecto a la malla refinada es **0,528 %**. Es una primera evidencia favorable de estabilidad puntual, pendiente de un refinamiento adicional. No es el promedio sobre la rejilla ni la componente σyy.

Ambos HTML nuevos todavía tienen fuerzas de 24,883 N, total vertical 46,764 N, y = 707 mm y gravedad activa. Por tanto, se mantiene la necesidad de reconciliar carga y referencia con el ensayo. Una comprobación nominal de ese caso da σ de flexión ≈ 10,981 MPa por fuerzas más peso de viga, o ≈ 11,019 MPa incorporando también el peso del herraje CAD idealizado. La cercanía apoya la plausibilidad del resultado bajo esa configuración; no constituye equivalencia exacta con Von Mises ni validación del ensayo. Cálculo, supuestos y fuentes están en `fem/mesh_study/actualizacion_2026-09-30/README.md`.

Se conservan los nuevos HTML y capturas originales; la auditoría pasa a nueve informes y las pruebas a ocho. El informe, ZIP y parche se actualizaron con esta evidencia.

## Opinión

Los cambios avanzan el proyecto: añaden el ensayo Samuel–Brayan, un análisis ejecutable, gráficas y una partición útil del CAD. La aritmética analítica y experimental del ZIP es correcta bajo sus hipótesis. **Todavía no es correcto declarar el trabajo validado ni la comparación FEM terminada.** La diferencia de aproximadamente 10–12 % debe explicarse con medidas y configuración verificables, no con porcentajes de incertidumbre supuestos.

## Resultados reproducidos

I = 33 105,33333 mm⁴; c = 15 mm; brazo CAD = 505,5 mm. Con 5,073 kg: P = 49,76613 N, M = 25 156,778715 N·mm, σyy = 11,398516 MPa y εyy = 165,195888 µε. Con solo la pesa de 5 kg: P = 49,05 N, σyy = 11,234493 MPa y εyy = 162,818734 µε.

El CSV tiene 7 744 muestras, 77,43 s y pasos de 0,01 s. La meseta de 24 a 53 s contiene 2 901 muestras; la base de 11 a 16,5 s contiene 551. Meseta = 185,31171 µε; base = 3,46042 µε; incremento = 181,85128 µε. Esfuerzo equivalente uniaxial = 12,547739 MPa. La diferencia es +10,08 % con el herraje añadido después del cero, o +11,69 % si estaba presente al poner en cero. El usuario indicó que no recuerda esa condición.

## Comparación y cambios aplicados

| Área | GitHub / ZIP recibido | Versión revisada |
|---|---|---|
| Ensayo | GitHub solo tenía otro archivo del grupo 1 | Se añade el CSV Samuel–Brayan y se conserva el anterior |
| CAD | Una cara de galga pasa a cuatro | STEP nuevo integrado; siete sólidos válidos, límites y volúmenes conservados; área total 75 mm² |
| Modelo analítico antiguo | `cos(20)` sin conversión, momento con F inclinada, nombres sin definir, extremos manuales | Entradas anteriores remiten al modelo corregido; P resultante, radianes y extremos calculados |
| Procesamiento nuevo | Ventanas fijas, filas descartadas sin diagnóstico, CSV localizado al importar | Ventanas configurables, validación de CSV/tiempos, funciones importables y resultados con SHA-256 |
| Cero experimental | Se asumía que viga sí y herraje no estaban incluidos | Ambos casos conservados y claramente condicionales |
| Esfuerzo | Se llamaba σx pese a eje longitudinal y; superficie libre equiparada a estado uniaxial | σyy; Eεyy condicionado a uniaxialidad; comparación FEM primaria en εyy |
| FEM | Nota del ZIP generalizaba 24,883 N a todas las corridas | Auditoría diferencia 49,05 N, 52,822 N y 46,764 N más gravedad |
| Mallas | Las exportaciones anteriores de 10 y 15 mm repetían resultados | Los HTML nuevos distinguen ambas resoluciones; los anteriores están archivados. La estabilidad puntual no equivale a convergencia definitiva |
| Incertidumbres | Porcentajes de galga, masa y peso propio sin trazabilidad | Se retiran; sensibilidad de espesor calculada y sin confundirla con incertidumbre medida |
| Informe | PDF con afirmaciones pendientes o demasiado fuertes | Fuente revisada; original archivado; conclusiones parciales y condiciones explícitas |

## Observaciones técnicas

**Magnitud FEM.** Una superficie libre en z = 30 mm no impone por sí sola σxx = 0: aún puede existir esfuerzo en el plano y cortante. En elasticidad isotrópica, εyy = [σyy − ν(σxx + σzz)]/E. La lectura más directa es la deformación longitudinal promediada en la rejilla, proyectada en su dirección real. Von Mises máximo del modelo no es la lectura experimental. [COMSOL: esfuerzo plano y ley constitutiva](https://www.comsol.com/blogs/what-is-the-difference-between-plane-stress-and-plane-strain/).

**Fuerzas remotas.** Autodesk permite definir magnitud, componentes, objetivo y punto remoto. Deben revisarse todos: una fuerza remota transfiere los efectos del punto especificado. Para P = 49,76613 N y 20°, la fuerza equivalente es 26,48000 N por lado; para P = 49,05 N, 26,09896 N. El peso del herraje no forma parte física de la tensión de cuerda que sostiene solo la pesa. Distribuirlo con las cuerdas es una equivalencia global y no un modelo local exacto del tornillo. [Autodesk: fuerzas remotas](https://help.autodesk.com/cloudhelp/ENU/Fusion-Simulate/files/SIM-REMOTE-FORCE-CONCEPT.htm).

**Convergencia.** Las exportaciones originales de 10 y 15 mm se conservan en `fem/mesh_study/historico_2026-09-25/`. Los máximos globales históricos son 17,535 / 20,453 / 21,018 / 21,018 / 20,863 MPa para 25 / 20 / 15 / 10 / 5 mm. El máximo no permite cerrar la convergencia en la galga. Los 80 346 nodos, 40 572 elementos y resúmenes iguales de 10 y 15 mm motivaron la reexportación ya incorporada el 30 de septiembre. El refinamiento nominal es insuficiente para describir la resolución local del espesor de 1 mm.

**Espesor.** Para el escenario de 5,073 kg, t = 0,95 mm da 11,947987 MPa (+4,82 %); t = 1,05 mm da 10,901594 MPa (−4,36 %); t = 0,90 mm da 12,558762 MPa. Esto es sensibilidad del modelo, no prueba de que el espesor sea 0,90 mm. No ajustar el espesor para hacer coincidir el ensayo. Medir también radios de esquina antes de corregir I.

**Cercanía a la mordaza.** La galga está aproximadamente a 63,67 mm del borde CAD. La teoría de viga es una referencia razonable de flexión global, pero los contactos y la restricción local deben comprobarse en FEM; no se afirma uniaxialidad exacta por la distancia o por estar en una cara libre.

**Materiales y masa CAD.** Los HTML usan E = 68 947,20 MPa y todo el herraje como aluminio 1100-O; el análisis usa 69 000 MPa. La diferencia de E es pequeña (0,077 %) y no explica por sí sola el desajuste. El volumen idealizado del herraje no acredita su masa experimental ni el material real.

## Validación realizada y límites

Se reprodujeron los resultados del CSV, la fuerza resultante y los extremos de rejilla; se comprobaron ventanas y errores de datos; se auditaron nueve HTML (incluidos dos anteriores archivados). Pasaron ocho pruebas automáticas. Se reimportaron los dos STEP con Open CASCADE y se verificaron sólidos, volúmenes, límites y caras de galga. Los CSV originales y HTML históricos se conservaron sin modificación. No se ejecutó FEM ni se verificó la configuración activa del `.f3d`.

El PDF de lectura se generó directamente a partir de los resultados verificados y se comprobó visualmente. La fuente LaTeX autónoma se mantiene abierta y editable; no se pudo verificar su compilación porque el editor integrado devolvió `Unable to find standard directories for platform`. El PDF no se presenta como salida de ese compilador.

Falta confirmar la conversión y factor de galga del canal, centro/orientación real de la rejilla, espesor y radios, carga/apoyo reales, contactos, suma de reacciones y convergencia de εyy en la galga. El estado de referencia no se puede reconstruir a partir del CSV solamente.

## Entrega

Se preparó una copia corregida del repositorio y un parche respecto al commit de referencia. La integración conserva las nuevas capturas e informes de 10 y 15 mm publicados en `main`. Los cambios revisados del ZIP se verifican antes de incorporarlos al repositorio mediante la sesión de GitHub del propietario.

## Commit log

2026-09-24 Añadir guía de Python
2026-09-24 Añadir cad
2026-09-24 Añadir cad/native
    [VIGA_FEM_editable.FCStd]
2026-09-24 Añadir cad/step
    [VIGA_FEM.step]
2026-09-24 Add files via upload
    1era version hay una falla al final del esfuerzo la cual toca corregir
2026-09-25 Update import math.py
    se corrigió el valor del como se calculaba la variable ¨M¨ y se coloco el valor de sigma promedio
2026-09-25 Update import math.py
    se cambio el punto de donde se ejerce la fuerza y la gravedad
2026-09-25 Add files via upload
    ya este es el paso a paso del proceso que se realizo con el que se baso para crear el codigo python y la base para seguir con la validación
2026-09-25 Update import math.py
    cambio de nombre del documento
2026-09-25 Rename import math.py to analytical_model.py
    cambio de nombre del archivo
2026-10-01 Actualizar informes y capturas de las mallas de 10 y 15 mm
    Incorporar los HTML y las dos capturas originales del 30 de septiembre de 2026. Documentar las lecturas de Von Mises y la comparación puntual entre ambas mallas.
2026-10-01 Retirar captura de 10 mm sustituida por el nuevo PNG
    La captura actual del estudio está en fem/mesh_study/10mm.png; la versión anterior permanece recuperable en el historial de Git.
2026-10-01 Retirar captura de 15 mm sustituida por el nuevo PNG
    La captura actual del estudio está en fem/mesh_study/15mm.png; la versión anterior permanece recuperable en el historial de Git.
2026-10-01 Integrar análisis, CAD e informe revisados de cambios_repo.zip (#1)
    Incorporar el ensayo Samuel–Brayan y su procesamiento reproducible, las gráficas, el CAD recibido, la auditoría FEM y el informe revisado. Conservar los dos escenarios de puesta a cero del herraje y 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
    Validación: ocho comprobaciones superadas y 38 archivos publicados verificados por SHA-256. Las dos capturas y los dos HTML actuales de las mallas de 10 y 15 mm se preservan. La validación física y l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
    [VIGA_FEM.step, VIGA_FEMa.f3d, Viga4SamuelBrayan.csv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]
2026-10-08 Integrar entrega final de GalgaLab y organizar evidencias
2026-10-14 Simplificar portada y estructura de GalgaLab
2026-10-15 Actualizar rutas de preservacion de archivos originales
